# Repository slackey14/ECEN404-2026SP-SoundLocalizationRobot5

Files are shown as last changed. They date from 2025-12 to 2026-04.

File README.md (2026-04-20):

# Sound Localization Robot 5, Team 23

**Sound Rover** is an autonomous, omnidirectional robot powered by an ESP32-S3 Wroom. It uses a 4-microphone array to localize target sound frequencies via Phase-Gradient TDOA (SRP-PHAT beamforming) and navigates toward them using A* path planning, mecanum wheels, and ultrasonic obstacle avoidance.

## Features
* **Acoustic Localization:** 4-mic SRP-PHAT beamforming for 360° sound direction finding and distance estimation.
* **Omnidirectional Drive:** Mecanum wheel control for complex maneuvering and strafing.
* **Autonomous Navigation:** Real-time A* path planning, mapping, and destination re-calculation on the fly.
* **Obstacle Avoidance:** 4x Ultrasonic sensors (Front, Back, Left, Right) via hardware-driven edge interrupts.
* **Web Interface:** Built-in WiFi Access Point and HTTP server providing a live web UI with map visualization, manual controls, and live DSP configuration.

## Hardware Architecture
* **Microcontroller:** ESP32-S3 WROOM 1
* **Microphones:** 4x I2S Digital Microphones
* **Sensors:** 6x Ultrasonic Distance Sensors
* **Chassis:** 4WD Mecanum Wheel chassis with independent motor drivers (PWM/Dir)

## Software Stack
* **Framework:** ESP-IDF / FreeRTOS (via PlatformIO)
* **Concurrency:** * **Core 0:** WiFi AP, HTTP Server, and Sound DSP Task (I2S DMA + FFT + SRP-PHAT).
  * **Core 1:** Navigation Task (A* Routing, Motor Control, Obstacle Detection).

## Getting Started
1. Flash the firmware to your ESP32-S3 using PlatformIO.
2. Power on the Rover.
3. Connect your device to the newly created WiFi Access Point: `Sound_Rover` (Open network).
4. Open a web browser and navigate to `http://192.168.4.1`.
5. From the Web UI, you can manually drive the rover, view the live localized obstacle map, or click **Chase Sound Source** to begin autonomous acoustic tracking.

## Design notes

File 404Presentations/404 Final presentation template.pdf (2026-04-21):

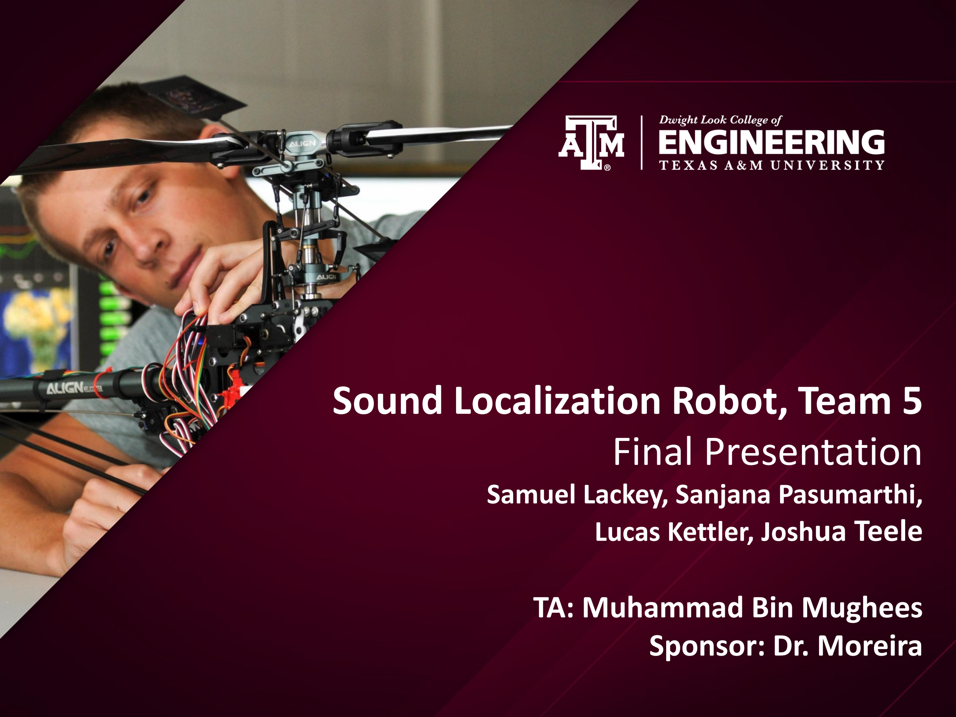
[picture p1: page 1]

# Sound Localization Robot, Team 5 Final Presentation

Samuel Lackey, Sanjana Pasumarthi,

# Lucas Kettler, Joshua Teele

# TA: Muhammad Bin Mughees Sponsor: Dr. Moreira

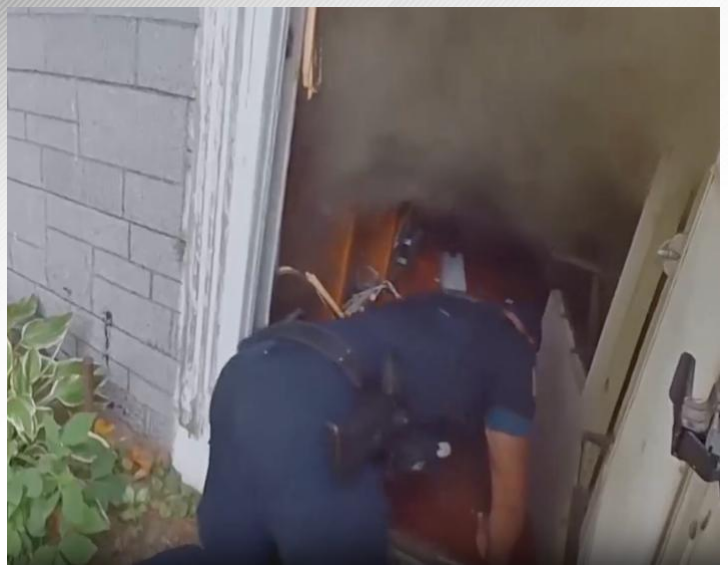
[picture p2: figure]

Figure 1. First responder crawls through smoke and broken glass to rescue elderly man from house fire (Independent TV)

# Problem: First Responders lack reliable methods for navigating dangerous environments, where visibility is limited, putting both their

safety and the victims at risk.

# Project Scope

# Our Solution: Building a Sound Localization robot that can hear distress calls, pinpoint their direction, and move toward them autonomously, allowing first responders to focus on saving lives

instead of risking theirs.

### •Keeps first responders safe by entering hazardous or toxic areas

first.

### •Reduces search and rescue time by avoiding exploring unnecessary paths •Reliable in low-visibility or high-

stress conditions (smoke, debris, noise).

*A smarter, safer, and faster way to locate victims, all while protecting rescuers and saving more lives.

# Integrated System Diagram:

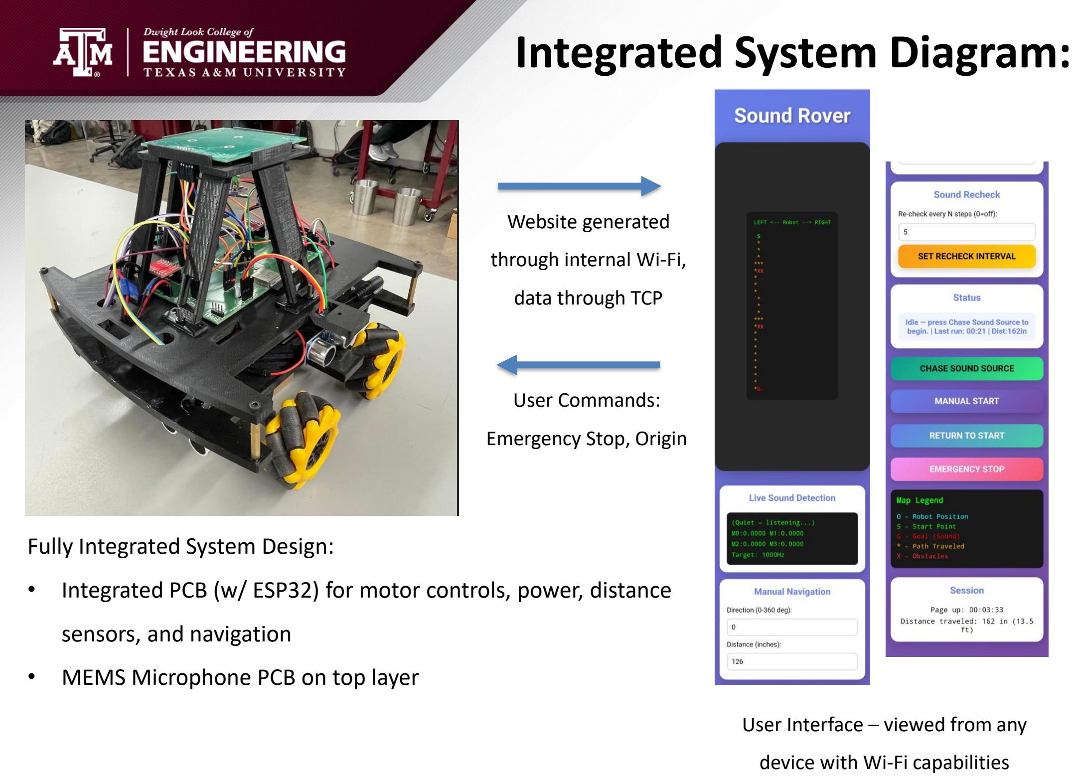
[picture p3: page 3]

## Fully Integrated System Design:

## - Integrated PCB (w/ ESP32) for motor controls, power, distance

## sensors, and navigation

## - MEMS Microphone PCB on top layer

### Website generated

through internal Wi-Fi,

### data through TCP

### User Interface – viewed from any

### device with Wi-Fi capabilities

### User Commands:

### Emergency Stop, Origin

# Navigation Software Subsystem Lucas Kettler

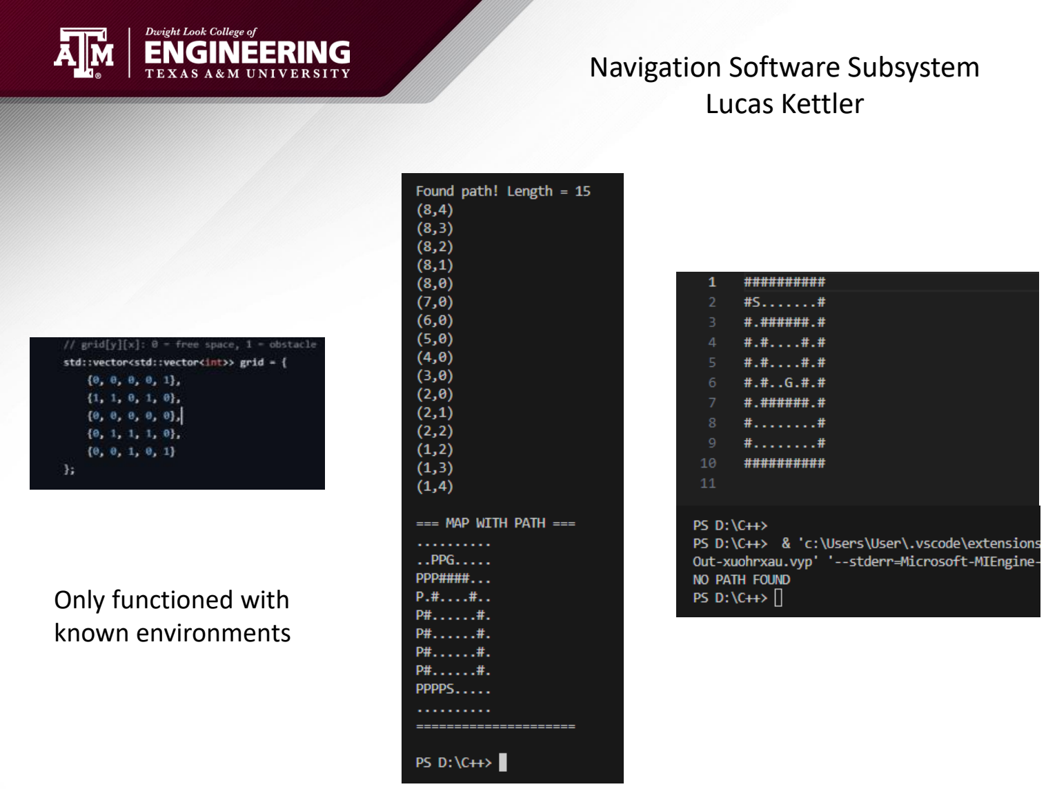
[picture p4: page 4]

## Only functioned with known environments

# Navigation Software Subsystem Lucas Kettler

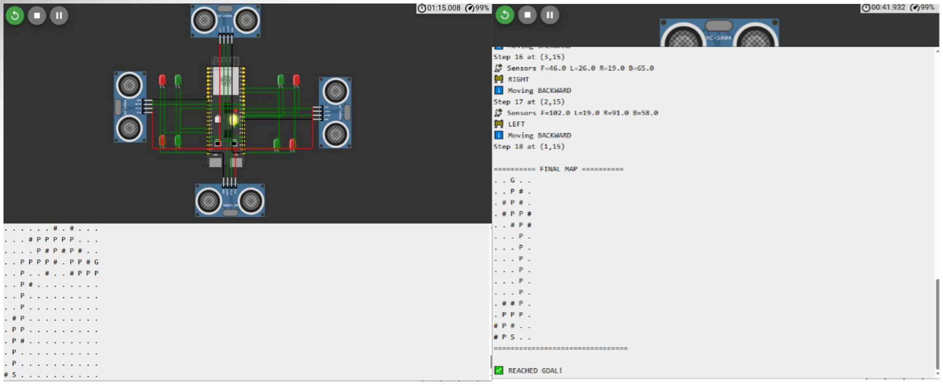
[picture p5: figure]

## No real world implementation at that time

# Navigation Software Subsystem Lucas Kettler

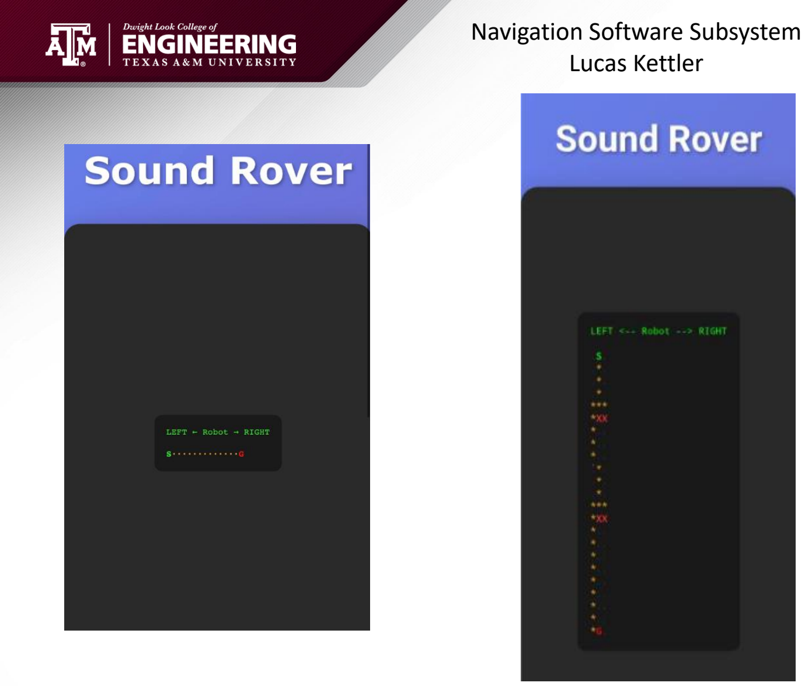
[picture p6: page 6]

# Motor Controls & Chassis Design & UI Subsystem Sanjana Pasumarthi

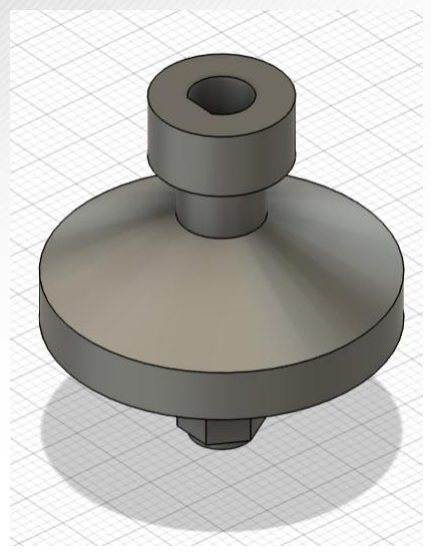
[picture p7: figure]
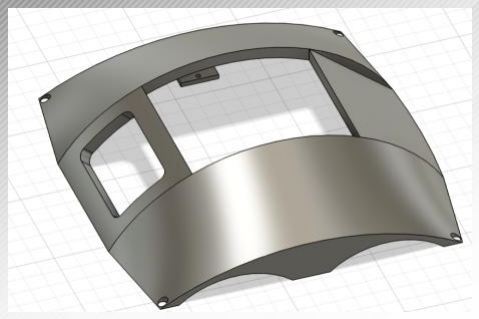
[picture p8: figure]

## - Physical Design of Rover - 2 layer Chassis Design - Strong Wheel axle - Dome Casing

## - Rover System - TCP socket generated from ESP Wi-fi - Webpage consists of multiple commands for user

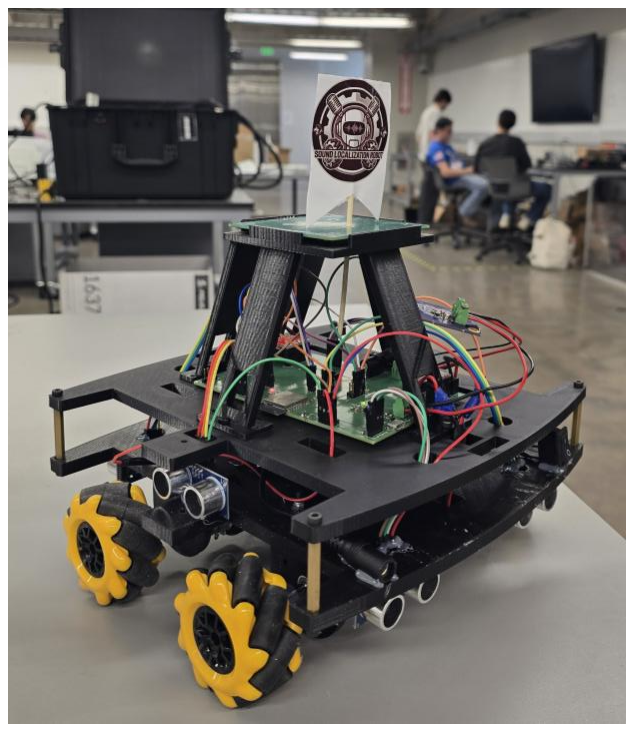
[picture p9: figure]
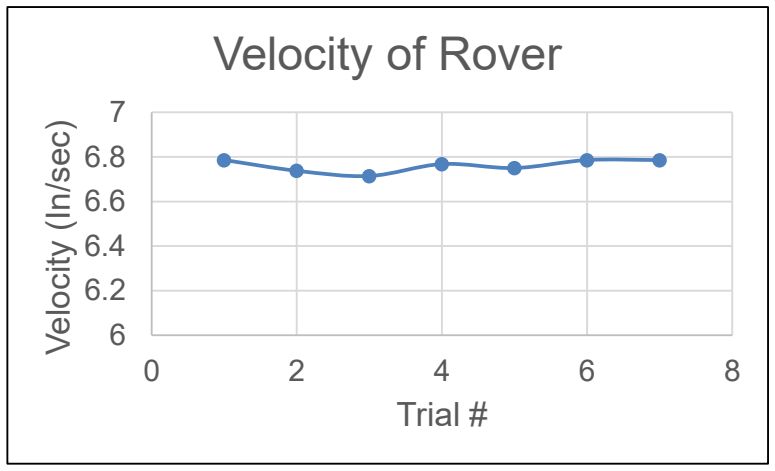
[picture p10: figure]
Velocity (In/sec); Trial #; Velocity of Rover

## Avg: 6.76 In/sec

# Motor Controls & Chassis Design & UI Subsystem

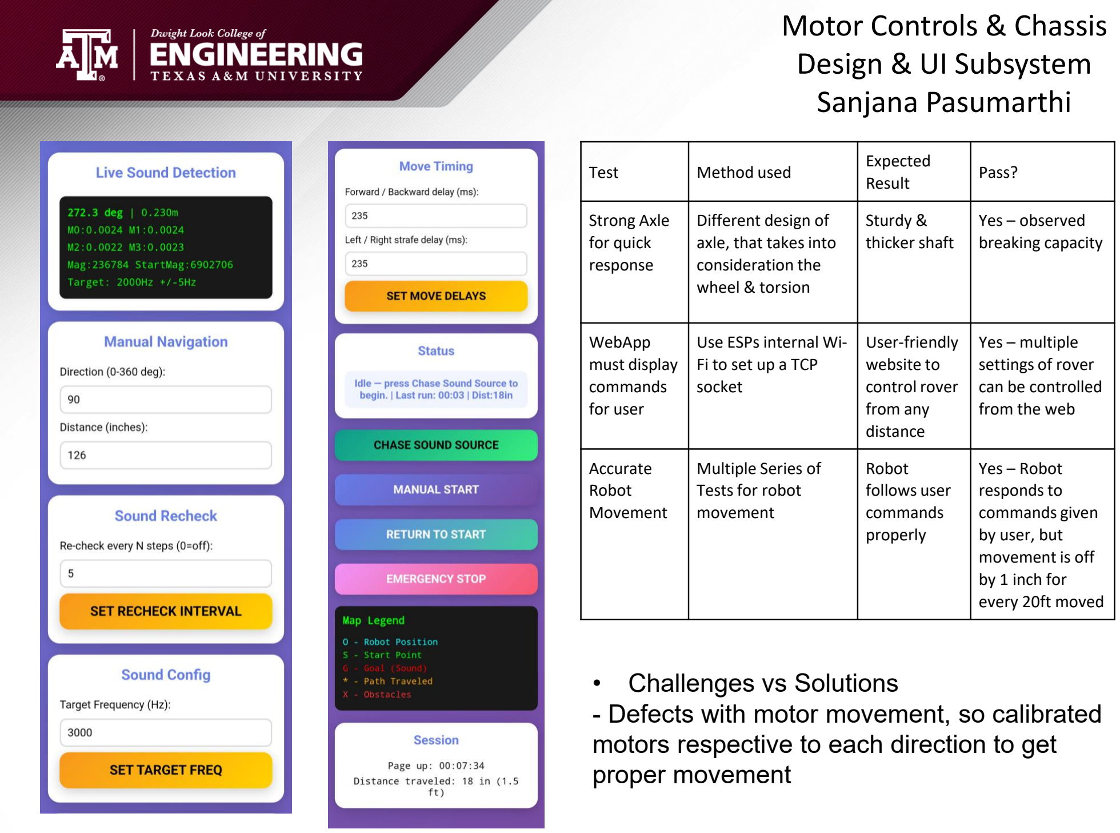
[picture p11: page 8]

# Sanjana Pasumarthi

Test | Method used | Expected Result | Pass?
Strong Axle for quick response | Different design of axle, that takes into consideration the wheel & torsion | Sturdy & thicker shaft | Yes – observed breaking capacity
WebApp must display commands for user | Use ESPs internal Wi-Fi to set up a TCP socket | User-friendly website to control rover from any distance | Yes – multiple settings of rover can be controlled from the web
Accurate Robot Movement | Multiple Series of Tests for robot movement | Robot follows user commands properly | Yes – Robot responds to commands given by user, but movement is off by 1 inch for every 20ft moved

## - Challenges vs Solutions - Defects with motor movement, so calibrated motors respective to each direction to get proper movement

# Input Signal Subsystem Samuel Lackey

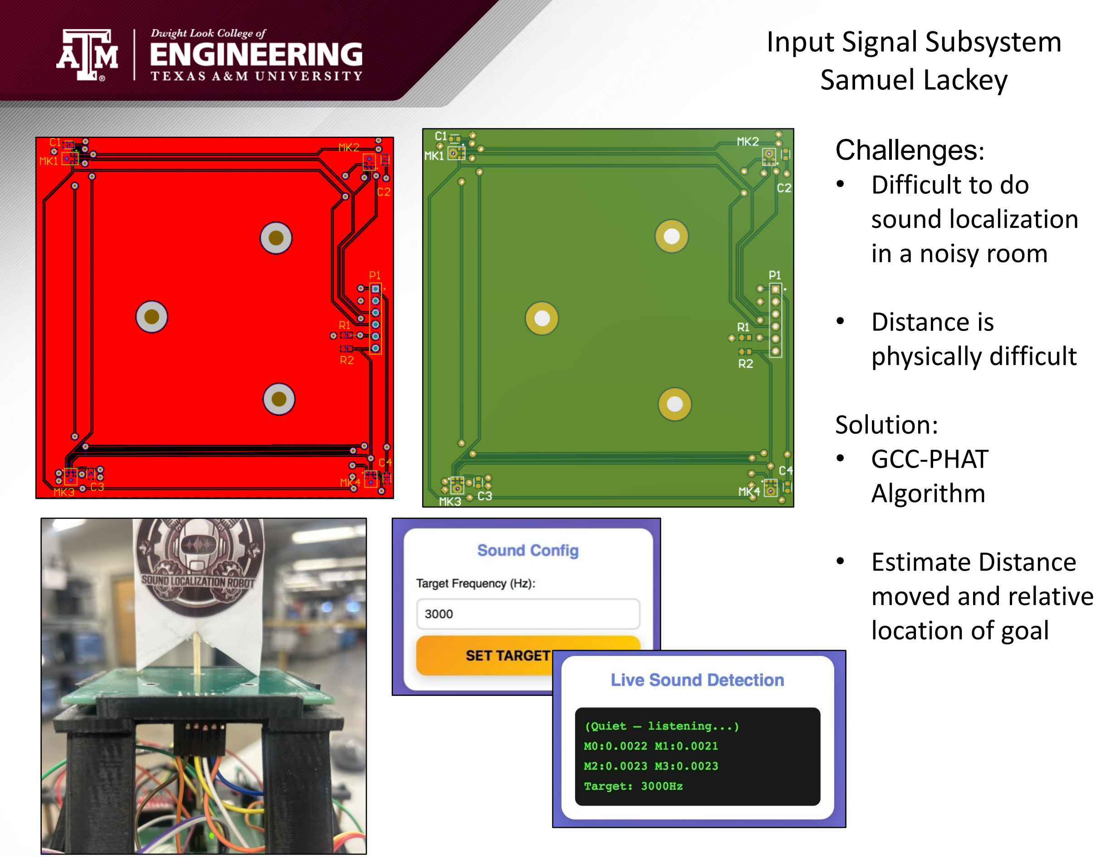
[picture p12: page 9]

## Challenges:

## - Difficult to do sound localization in a noisy room

## - Distance is physically difficult

## Solution: - GCC-PHAT Algorithm

## - Estimate Distance moved and relative location of goal

Test | Pass?
Microphone gives radial angle < 15° | 0° - ✓ 90° - ✓ 180° - ✓ 270° - ✓

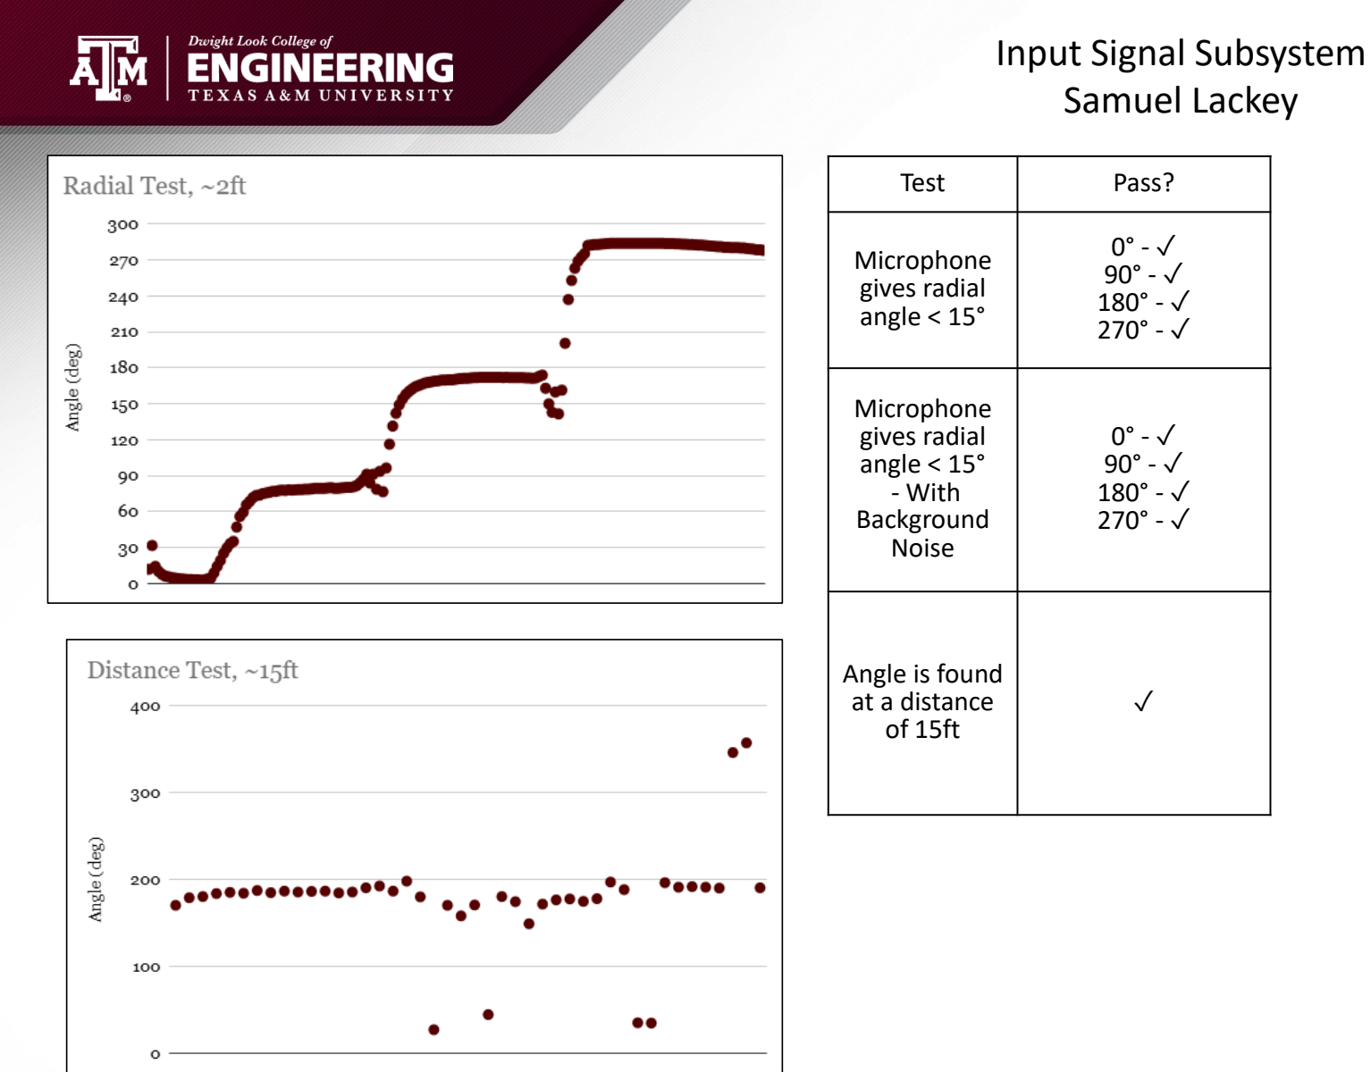
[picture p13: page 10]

Microphone gives radial angle < 15° - With Background Noise | 0° - ✓ 90° - ✓ 180° - ✓ 270° - ✓
Angle is found at a distance of 15ft | ✓

# Input Signal Subsystem Samuel Lackey

# Power & Distance Sensor & MCU Subsystem Joshua Teele

## Diagram of Power Flow in Whole System

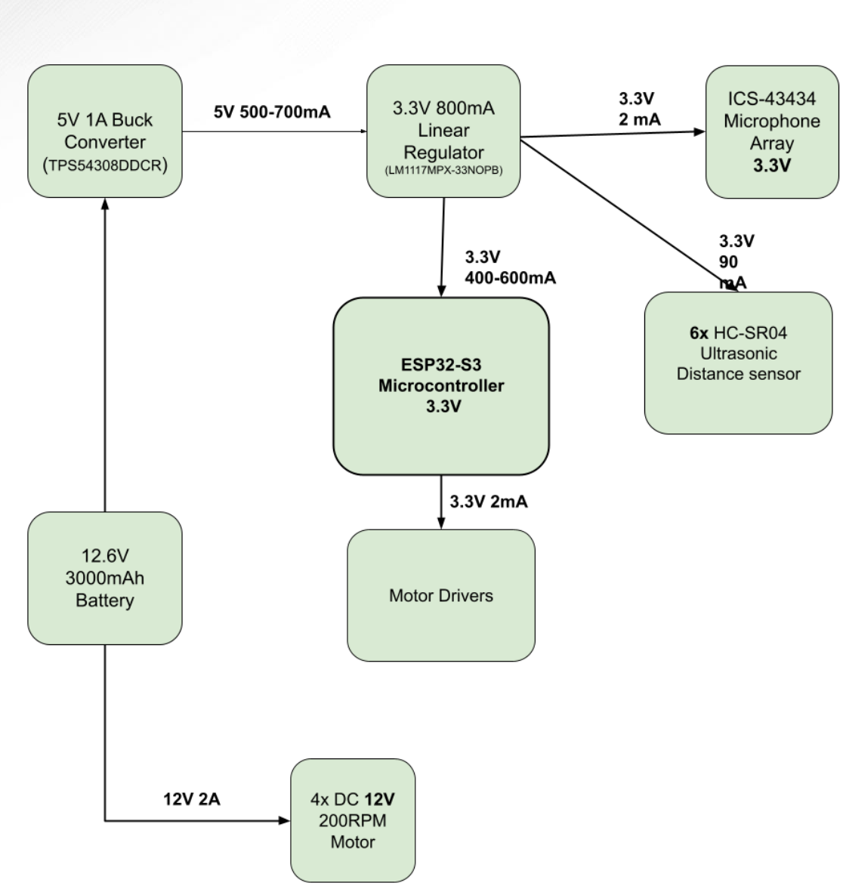
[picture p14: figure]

# Power & Distance Sensor & MCU Subsystem

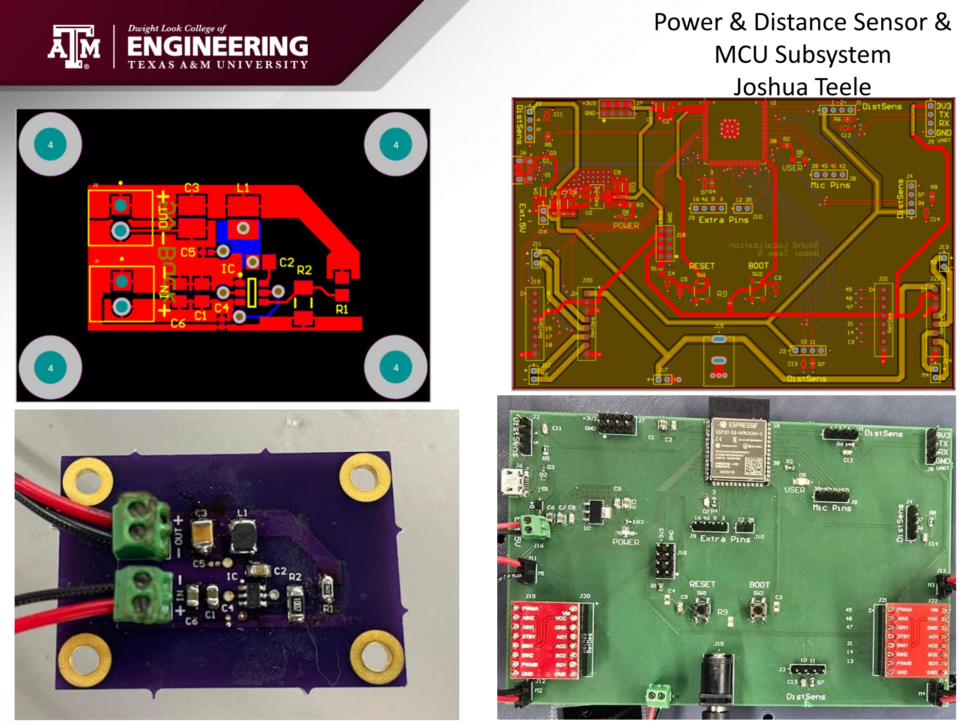
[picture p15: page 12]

# Joshua Teele

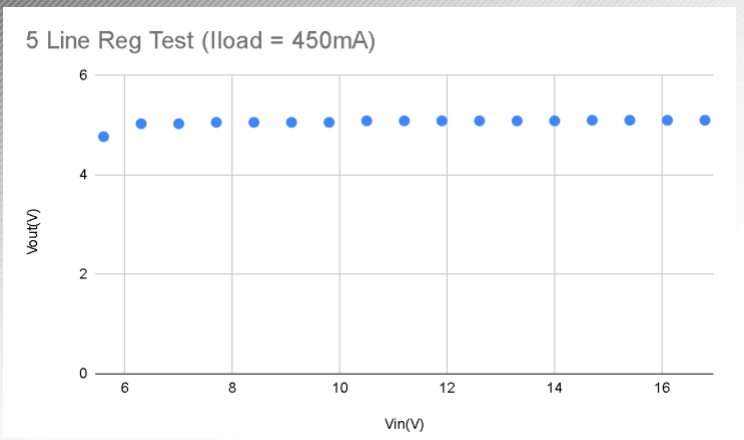
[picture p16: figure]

Test | Distance used | Expected Result | Pass?
Sensor outputs hig h when distance < 25.4 cm | 15 cm | High on all sensors | Sensor 1 - ✓ Sensor 2 - ✓ Sensor 3 - ✓ Sensor 4 - ✓
Sensor outputs low when distance > 25.4 cm | 35 cm | Low on all sensors | Sensor 1 - ✓ Sensor 2 - ✓ Sensor 3 - ✓ Sensor 4 - ✓

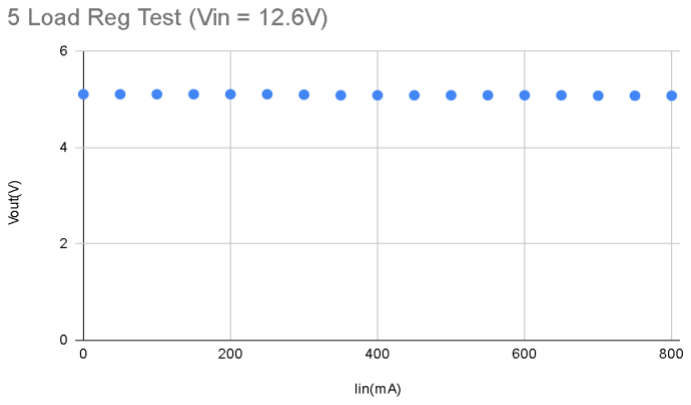
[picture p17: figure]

What happens at the bound ary for sensor | 25.4 cm | High on all sensors | Sensor 1 - High Sensor 2 - High Sensor 3 - High Sensor 4 - High
Slightly under boundary | 24.5 cm | Low on all sensors | Sensor 1 - ✓ Sensor 2 - ✓ Sensor 3 - ✓ Sensor 4 - ✓

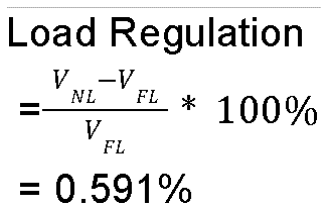
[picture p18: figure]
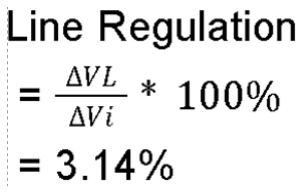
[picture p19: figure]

Slightly over boundary | 26.4 cm | High on all sensors | Sensor 1 - ✓ Sensor 2 - ✓ Sensor 3 - ✓ Sensor 4 - ✓
Multiple sensors | 25.4 cm | High on all combinations | ✓

# Power & Distance Sensor & MCU Subsystem Joshua Teele

## Challenges: - Placement of distance sensors to avoid obstacles

## Solutions: - Put on front and back where it can catch blind spots

# Power & Distance Sensor & MCU Subsystem

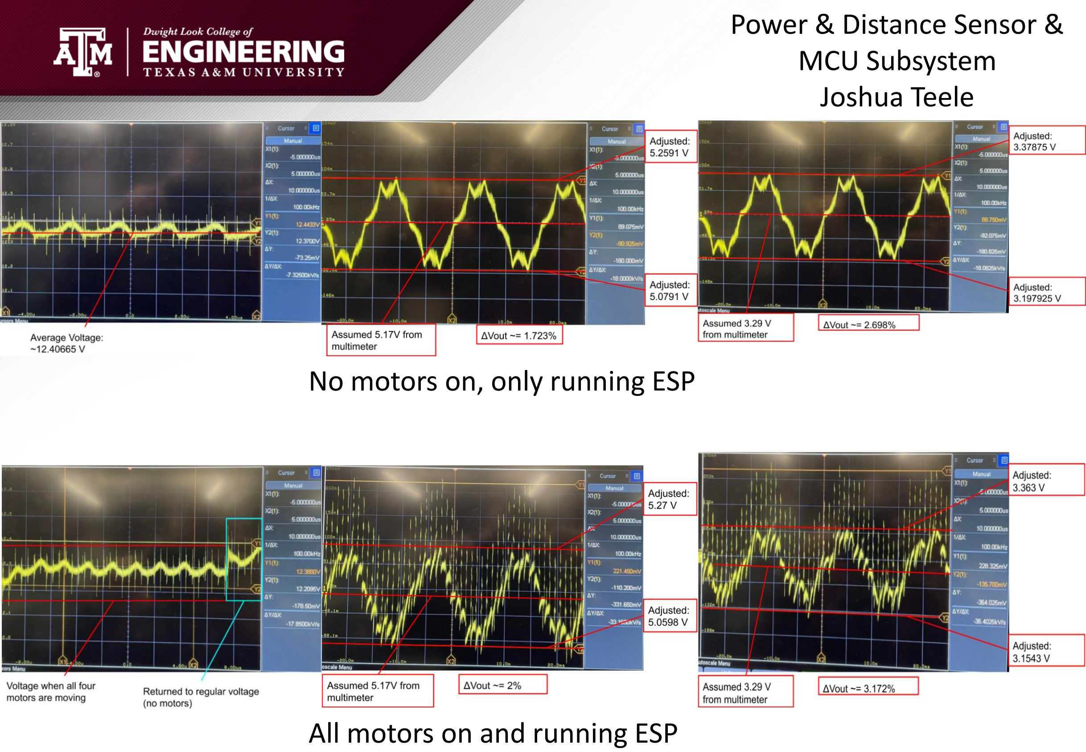
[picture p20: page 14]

# Joshua Teele

# No motors on, only running ESP

# All motors on and running ESP

# System

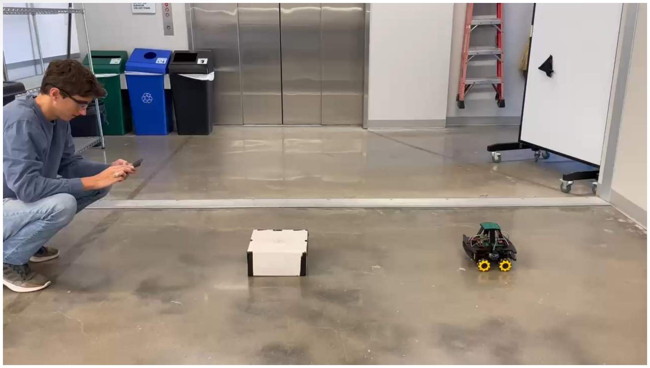
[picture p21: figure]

# System Testing

Test | Results

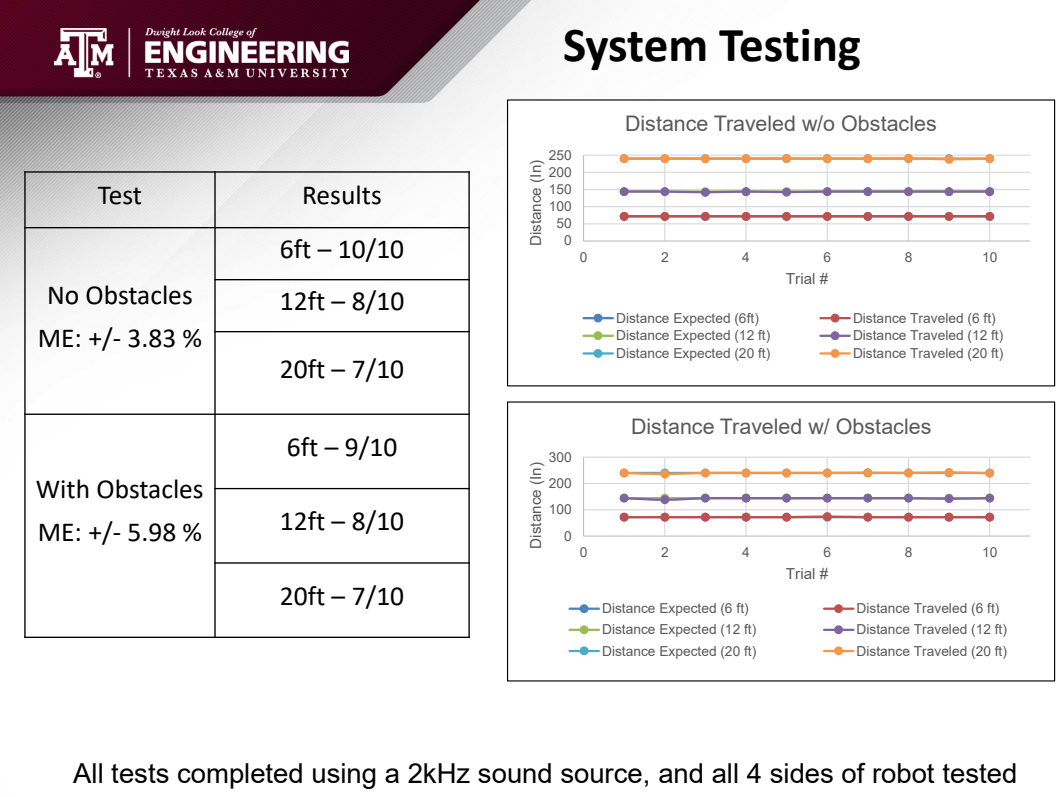
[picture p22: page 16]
With Obstacles; Distance (In); Trial #; Distance Expected (6ft); Distance Traveled (6 ft); Distance Expected (12 ft); Distance Traveled (12 ft); Distance Expected (20 ft); Distance Traveled (20 ft); Distance Expected (6 ft)

Distance Traveled w/o Obstacles

No Obstacles ME: +/- 3.83 % | 6ft – 10/10

Distance Traveled w/ Obstacles

All tests completed using a 2kHz sound source, and all 4 sides of robot tested

# Changes from 403:

# - Additional Distance Sensors

# - No 3.3 V Buck Converter

# - No Hall effect sensors

# - Using designed PCB Mic

# Array

# Current Status:

# - Integration Complete

# - Validation Complete

# - Finishing Touches such as

# addressing slight motor

# drift, and map display

# Conclusions

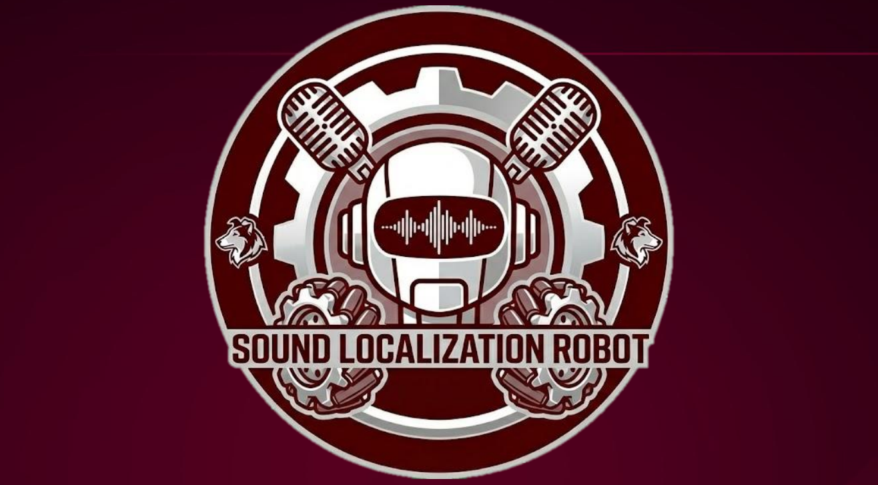
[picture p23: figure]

Thank You,

# Any Questions?

# Sound Localization Robot 5 – Team 23

# Lucas Kettler, Samuel Lackey, Joshua Teele, Sanjana Pasumarthi

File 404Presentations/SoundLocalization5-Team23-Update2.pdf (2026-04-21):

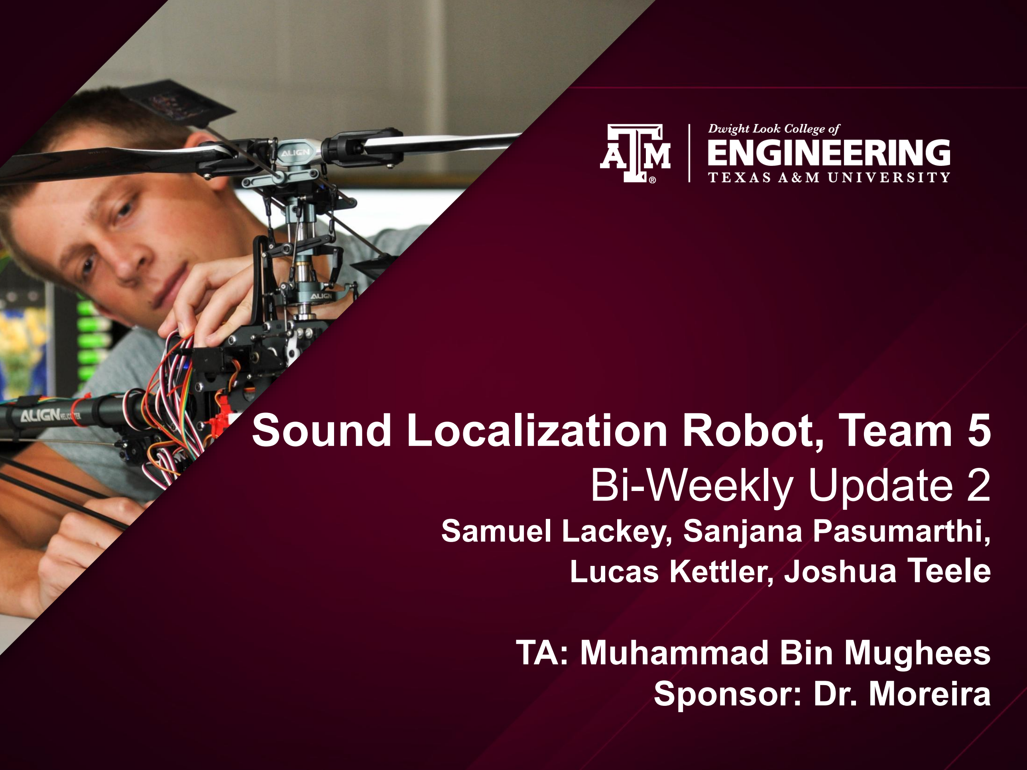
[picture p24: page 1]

# Sound Localization Robot, Team 5 Bi-Weekly Update 2

Samuel Lackey, Sanjana Pasumarthi,

### Lucas Kettler, Joshua Teele

## TA: Muhammad Bin Mughees Sponsor: Dr. Moreira


Figure 1. First responder crawls through smoke and broken glass to rescue elderly man from house fire (Independent TV)

### Problem: First Responders lack reliable methods for navigating dangerous environments, where visibility is limited, putting both their

safety and the victims at risk.

# Project Scope

### Our Solution: Building a Sound Localization robot that can hear distress calls, pinpoint their direction, and move toward them autonomously, allowing first responders to focus on saving lives

instead of risking theirs.

•Keeps first responders safe by entering hazardous or toxic areas first.
•Reduces search and rescue time by avoiding exploring unnecessary paths
•Reliable in low-visibility or high-stress conditions (smoke, debris, noise).

*A smarter, safer, and faster way to locate victims, all while protecting rescuers and saving more lives.

# Robot Sub Systems:


# Project Timeline


# Input Signal Software

Samuel Lackey
Accomplishments since last update : 15 Hours of Effort

Ongoing progress/problems and plans until the next presentation
- Completed Microphone Array PCB
- Adapted Sound Localization Algorithm into a single callable function
- Fully incorporate Signal Processing code into navigation subsystem

# Input Signal Software


Samuel Lackey

Microphone Array PCB Schematic

Microphone Array PCB 3D Design

Microphone Array
PCB Design

# Mechanical/ Motor Controls Subsystem

Sanjana Pasumarthi
Accomplishments since Last Update 12 hours of effort | Ongoing progress/problems and plans until the next presentation
- Completed 3D prints of all parts • Integrated some parts of the navigation system with the motor controls | • Still working on integrating the code with Lucas • Have the webapp’s UI complete and display the data (magnitude & direction, pathway, time duration)

# Mechanical/ Motor Controls Subsystem


Sanjana Pasumarthi

- Two-part set up to hold the isolated microphone array
- Top stand is screwed onto the top layer of the chassis
- Set-up the Wi-Fi module for the webapp, still working on the UI
- Implemented necessary
pauses before the motors’
changes direction

# Navigation Software Subsystem

Lucas Kettler
Accomplishments since Last Update 8 hrs of effort | Ongoing progress/problems and plans until the next presentation
- Integration of Motor Controls (Untested) • Integration of Webapp (Untested) | • Validate integration of Motor controls and webapp • Integration of code with Input Software/Sensor Software Code

### Navigation Software Subsystem Lucas Kettler


# Power & Distance Sensor Subsystem

Joshua Teele
Accomplishments since Last Update
10 hrs of effort

Ongoing progress/problems and plans until the next presentation
- Completed PCB design of MCU
- Ordered MCU PCB and
components
- Solder PCB and test with multimeter
- Test individual subsystems on new MCU
- Ongoing: Integrate distance sensor code with navigation software

# Power & Distance Sensor Subsystem


Joshua Teele

# Parts and PCB

Part | Est. Arrival
MCU PCB | Feb 6th
Components for MCU PCB | Acquired
Microphone Array PCB | Feb 10th
Components for Mic Array PCB | Feb 10th

# Execution Plan


# Validation Plan


Thank You,

# Any Questions?

## Sound Localization Robot 5 – Team 23

Lucas Kettler, Samuel Lackey, Joshua Teele,

## Sanjana Pasumarthi

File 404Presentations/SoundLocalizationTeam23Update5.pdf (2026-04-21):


## Team 23: Sound Localization Robot Bi-Weekly Update 5

Samuel Lackey, Sanjana Pasumarthi, Lucas Kettler,

### Joshue Teele

### Sponsor: Dr. Moreira TA: Muhammed Bin Mughees


Figure 1. First responder crawls through smoke and broken glass to rescue elderly man from house fire (Independent TV)

### Problem: First Responders lack reliable methods for navigating dangerous environments, where visibility is limited, putting both their

safety and the victims at risk.

# Project Scope

### Our Solution: Building a Sound Localization robot that can hear distress calls, pinpoint their direction, and move toward them autonomously, allowing first responders to focus on saving lives

instead of risking theirs.

•Keeps first responders safe by entering hazardous or toxic areas first.
•Reduces search and rescue time by avoiding exploring unnecessary paths
•Reliable in low-visibility or high-stress conditions (smoke, debris, noise).

*A smarter, safer, and faster way to locate victims, all while protecting rescuers and saving more lives.

# Project Timeline

Subsystem
Designs and
Testing
(completed
1/29)

Integration of
Motor Control,
Navigation
(completed
2/5)

Integration of
Sound
Algorithm,
Navigation
(completed
2/19)

Final
Integration
(completed
3/3)

System Test
(completed
3/10)

Validation
(to complete
by 3/31)

Demo and
Report
(to complete
by 4/5)

# SYSTEM Validation Plan


# Validation

3.2.2.1 Accurate Robot
Movement

Robot moves in intended direction determined by program

Series of coordination
tests for the robot to
move to the sound
source

TESTED Full
Team

Robot moves roughly 1m off every 20m in testing. This can be fine tuned in code

3.2.2.3 Structurally strong Robot

Wheel shaft does not break easily, no unintended movement from motors

Test robot with obstacles
and quick movement | TESTED | Sanjana

3.2.2.2

Constant
Response rate of
robot

Robot has a constant rate of response with +/- 5% of average time

Multiple trials of measuring time it takes for rover to change status

NOT
TESTED

Full
Team

Stronger shafts hold more weight and pressure, naturally fits into wheel for more grip, removing need for adhesive

# Validation

Map updated seamlessly with the live movements, with and without obstacles while showing distance travelled

3.2.1. 3 | Obstacle Detection | Verify robot halts movement at the node prior to an object | Isolated test with robot trying to drive around obstacle to a goal | TESTED | Lucas, Joshua, Sanjana
3.2.1. 4 | Grid Mapping | Verify the robot updates a grid map for the web app | completion of path View output of webapp upon | TESTED | Lucas, Sanjana
3.2.1. 5 | Webapp | The webapp must show the angle, estimate distance, and control the robot. | Run the program and connect to Wi-Fi, access the webapp, and move. | TESTED | Sam, Sanjana


# Validation

It’s difficult to achieve true perfect angle calculation in noisy rooms, but robot will still detect sound source well.

3.2.1.1 | DOA Angle Accuracy | All 5 tests must log a detected angle within an 3.6° | Place speaker playing 450Hz tone at a known angle, and 0.5m distance. Run the detection test 5 times | TESTED | Sam
3.2.1.2 | DOA With Backgrou nd Noise | All 5 tests must log a detected angle within an 3.6° | Place speaker playing 450Hz tone at a known angle, and 0.5m distance while separate 550Hz tone is playing. Repeat 5 times | UNTESTED | Sam
3.2.1.6 | Robot Distance | The robot must finish moving < 0.5 m from the sound source. | Play the sound source, allow the robot to move at different distances and angles. | TESTED | Sam


# Validation


3.2.3. 3.1 | Input Voltage(US B) | Ensure voltage at USB port is above 4.75V (minimum needed voltage for linear regulator) | Use multimeter to test output of buck converter | TESTED | Joshua
3.2.3. 3.2 | Input Voltage(DC jack) | Ensure voltage at DC jack is between 10.8 and 13.2 V (+/-10% of motor voltage) | Use multimeter to test output of DC jack | TESTED | Joshua

# Integrated System Diagram:


Fully Integrated System Design:

- Integrated PCB (w/ ESP32) for motor

controls, power, distance sensors, and

navigation

- Microphone PCB on top layer (not displayed)

Website generated

through internal Wi-Fi

User Interface – viewed from any

device with Wi-Fi capabilities

User Commands:

Emergency Stop, Origin

# Input Signal Software

Samuel Lackey
Accomplishments since last update : 20 Hours of Effort | Ongoing progress/problems and plans until the next presentation
- Fully Integrated and tested new microphone PCB with the robot. | • Continue testing, and improving • I need to work out edge cases and reliability

# Mechanical/ Motor Controls Subsystem

Sanjana Pasumarthi

Accomplishments since last update 15 hrs of effort | Ongoing progress/problems and plans until the next presentation
- Validated Structural Integrity of chassis design • Completed UI • Validated movement of motors corresponding to their movement | • On-going tests to determine optimal duration of motors for accurate movement • Designing casing to cover set-up

# Navigation Software Subsystem

Lucas Kettler

Accomplishments since last update 13 hrs of effort

Ongoing progress/problems and plans until the next presentation

- Validated Grid map live updates
- Added a run timer and return to start function
- Assisted in tests of varying distances with and without obstacles
- Validate Grid map expansion for demo

# Power & Distance Sensor Subsystem

Joshua Teele

Accomplishments since Last Update 12 hrs of effort | Ongoing progress/problems and plans until the next presentation
- Helped other work on fully integrated robot • Changed up wiring on the chassis to make it look neater | • Keep testing and sort out any issues with robot

# Execution Plan



Thank You,

# Any Questions?

## Sound Localization Robot 5 – Team 23

Lucas Kettler, Samuel Lackey, Joshua Teele,

## Sanjana Pasumarthi

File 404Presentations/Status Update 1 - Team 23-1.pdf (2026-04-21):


## Sound Localization Robot 5, Team 23

Samuel Lackey, Sanjana Pasumarthi,

### Lucas Kettler, Joshua Teele

## TA: Muhammad Bin Mughees Sponsor: Dr. Moreira


Figure 1. First responder crawls through smoke and broken glass to rescue elderly man from house fire (Independent TV)

### Problem: First Responders lack reliable methods for navigating dangerous environments, where visibility is limited, putting both their

safety and the victims at risk.

# Project Scope

### Our Solution: Building a Sound Localization robot that can hear distress calls, pinpoint their direction, and move toward them autonomously, allowing first responders to focus on saving lives

instead of risking theirs.

•Keeps first responders safe by entering hazardous or toxic areas first.
•Reduces search and rescue time by avoiding exploring unnecessary paths
•Reliable in low-visibility or high-stress conditions (smoke, debris, noise).

*A smarter, safer, and faster way to locate victims, all while protecting rescuers and saving more lives.

# Robot Sub Systems:


# Major Project Implementations for 404

- No longer using 3.3V buck converter
- Changed from circular mic array to new designed mic

array

- Integrated webapp with information portraying:

location, angle, distance, current direction movement,

alert user once destination is reached, and controls.

- Robot will move to sound source in & out of sight,

and avoid obstacles

- Robot movement with periodical listening capability

# Project Timeline


# Input Signal Software

Samuel Lackey
Accomplishments since 403
5 Hours of Effort

Ongoing progress/problems and plans until the next presentation
- Algorithm detects angles within 3.6°
- A specific frequency can be isolated
- A rough distance can be
calculated
- Completed schematic for
Microphone Array
- Complete PCB layout for
microphone array
- Work with Lucas to merge codebase

# Input Signal Software


Samuel Lackey

Microphone Array PCB Schematic

Microphone Array Angle Test

# Mechanical/ Motor Controls Subsystem

Sanjana Pasumarthi
Accomplishments since 403
6 hours of effort

Ongoing progress/problems and plans until the next presentation
- Sound rover moves in all directions, given the remote command from website, in-built LED to show connectivity status
- All parts such as the base, motor clamps and wheel shafts are 3D printed
- Established local Wi-Fi
connection on ESP32, stable at 20 feet radius, response speed of 0.24 seconds
- Have a verified design for an PCB that integrates the power and the motor controls
- Integrating the motor control firmware with the navigation & input signal software
- Update design & 3D print parts for rover

# Mechanical/ Motor Controls Subsystem

Sanjana Pasumarthi; Linear Velocity; (Ft/Sec); Trial #; 16 Velocity ⁽Ft/ Sec⁾; 16 Velocity ⁽Ft/Sec⁾; Diagonal Trials; Diagonal Directions; Angular Velocity; (Rad/sec); Sec); Mean: 3.4305 +/- 0.0126 Rad/Sec; Time (Sec); Feet; Trial #1; Trial #2; Trial #3; Mean: 0.243 +/- 0.0457 Sec

Velocity (Ft/Sec)

Mean: 2.4831 +/- 0.0064 Ft/ Sec

Forward/ Backward Directions

*measured distance of 6.5 ft

Mean: 2.3135 +/- 0.0258 Ft/ Sec

Left/ Right Directions

Mean: 1.7158 +/- 0.0173 Ft/ Sec

*measured distance of 1 ft

Recieved Command Time (Sec)

Angular Velocity (Rad/

Linear Velocity (3.5 in. ~ 0.2961 ft)
Mean: 0.1592 +/- 0.0005 Ft/Sec

*measured time for one complete
rotation (2*π radians)

# Navigation Software Subsystem

Lucas Kettler
Accomplishments since 403 6 hrs of effort | Ongoing progress/problems and plans until the next presentation
- Implementation of incremental A* algorithm with grid mapping and real time expansion • Wide range of simulations completed using LEDs and simulated sensor input | • Integration of code with Motor Controls/WebApp Code • Integration of code with Input Software Code

### Navigation Software Subsystem Lucas Kettler


## - Red LED – Backwards - Green LED – Forwards - Yellow LED – Obstacle - Logic works as intended but requires many changes to be adapted to a real-world robot

# Power & Distance Sensor Subsystem

Joshua Teele
Accomplishments since 403 6 hrs of effort | Ongoing progress/problems and plans until the next presentation
- Completed schematic for MCU PCB • Designed, soldered, and tested 3.3V and 5V buck converter (403) • Created code for distance sensors (403) | • Finish designing and routing MCU PCB • Integrate distance sensor code with navigation software

# Power & Distance Sensor Subsystem


Joshua Teele

# Parts and PCB

Part | Est. Arrival
MCU PCB | Feb 26th
Components for MCU PCB | Feb 19th
Microphone Array PCB | Feb 26th
4x ICS-43434 Mics | Feb 19th
4x 0.1µF Capacitor | Feb 19th

# Execution Plan


# Validation Plan


Thank You,

# Any Questions

## Sound Localization Robot 5 – Team 23

Lucas Kettler, Samuel Lackey, Joshua Teele,

## Sanjana Pasumarthi

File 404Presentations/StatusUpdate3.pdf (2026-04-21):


# Sound Localization Robot, Team 5 Bi-Weekly Update 3

Samuel Lackey, Sanjana Pasumarthi,

### Lucas Kettler, Joshua Teele

## TA: Muhammad Bin Mughees Sponsor: Dr. Moreira


Figure 1. First responder crawls through smoke and broken glass to rescue elderly man from house fire (Independent TV)

### Problem: First Responders lack reliable methods for navigating dangerous environments, where visibility is limited, putting both their

safety and the victims at risk.

# Project Scope

### Our Solution: Building a Sound Localization robot that can hear distress calls, pinpoint their direction, and move toward them autonomously, allowing first responders to focus on saving lives

instead of risking theirs.

•Keeps first responders safe by entering hazardous or toxic areas first.
•Reduces search and rescue time by avoiding exploring unnecessary paths
•Reliable in low-visibility or high-stress conditions (smoke, debris, noise).

*A smarter, safer, and faster way to locate victims, all while protecting rescuers and saving more lives.

# Robot Sub Systems:


# Project Timeline


# Input Signal Software

Samuel Lackey
Accomplishments since last update : 15 Hours of Effort

Ongoing progress/problems and plans until the next presentation
- Completed Microphone Array PCB
- Adapted Sound Localization Algorithm into a single callable function
- Fully incorporate Signal Processing code into Navigation subsystem
- The new Microphone PCB is not fully functional yet

# Input Signal Software


Samuel Lackey

Microphone Array PCB 3D Design

Microphone Array PCB

Only 2/4 Mics are
outputting data
- Check solder connections
- Resolder non-functional
mics

# Mechanical/ Motor Controls Subsystem

Sanjana Pasumarthi
Accomplishments since Last Update 11 hours of effort | Ongoing progress/problems and plans until the next presentation
- Set back with some of the components failing, had to order replacements and rewire for testing • Basic UI is complete to display information | • Program a method to record pathway trace for the rover to return to its origin • Integrating the controls with Lucas’s Code

# Mechanical/ Motor Controls Subsystem

Sanjana Pasumarthi


- Final UI design of website accessible through connect of ESP wifi module
- Includes emergency stop, pathway of rover, return to origin button, magnitude and direction of sound source

# Navigation Software Subsystem

Lucas Kettler

Accomplishments since Last Update 10 hrs of effort | Ongoing progress/problems and plans until the next presentation
- Partial integration of Input software/webapp • Integration of Sensor code | • Validate integration of subsystems • Debug integration components

### Navigation Software Subsystem Lucas Kettler


# Power & Distance Sensor Subsystem

Joshua Teele
Accomplishments since Last Update 10 hrs of effort | Ongoing progress/problems and plans until the next presentation
- Solder PCB and test with multimeter • Tested distance sensor code on new MCU | • Test rest of individual subsystems on new MCU • Ongoing: Integrate distance sensor code with navigation software

# Power & Distance Sensor Subsystem

Joshua Teele


# Execution Plan


# Validation Plan


Thank You,

# Any Questions?

## Sound Localization Robot 5 – Team 23

Lucas Kettler, Samuel Lackey, Joshua Teele,

## Sanjana Pasumarthi

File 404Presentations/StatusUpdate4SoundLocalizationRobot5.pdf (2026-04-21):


# Sound Localization Robot, Team 5 Bi-Weekly Update 4

Samuel Lackey, Sanjana Pasumarthi,

### Lucas Kettler, Joshua Teele

## TA: Muhammad Bin Mughees Sponsor: Dr. Moreira


Figure 1. First responder crawls through smoke and broken glass to rescue elderly man from house fire (Independent TV)

### Problem: First Responders lack reliable methods for navigating dangerous environments, where visibility is limited, putting both their

safety and the victims at risk.

# Project Scope

### Our Solution: Building a Sound Localization robot that can hear distress calls, pinpoint their direction, and move toward them autonomously, allowing first responders to focus on saving lives

instead of risking theirs.

•Keeps first responders safe by entering hazardous or toxic areas first.
•Reduces search and rescue time by avoiding exploring unnecessary paths
•Reliable in low-visibility or high-stress conditions (smoke, debris, noise).

*A smarter, safer, and faster way to locate victims, all while protecting rescuers and saving more lives.

# Integrated System Diagram:


Fully Integrated System Design:

- Integrated PCB (w/ ESP32) for motor

controls, power, distance sensors, and

navigation

- Microphone PCB on top layer (not displayed)

Website generated

through internal Wi-Fi


User Interface – viewed from

any device with Wi-Fi

capabilities

User Commands:

Emergency Stop, Origin

# Project Timeline


# Input Signal Software

Samuel Lackey
Accomplishments since last update : 35 Hours of Effort

Ongoing progress/problems and plans until the next presentation

- Soldered on Microphone PCB
- Tested Algorithm on new PCB
- Integrated algorithm into team’s

code

- Continue testing, and improving
- Not very accurate with current

implementation – Need to smooth

more for direction

# Input Signal Software


Samuel Lackey

Microphone Array PCB 3D Design

Microphone Array PCB

All Mics are now working as expected

# Mechanical/ Motor Controls Subsystem

Sanjana Pasumarthi
Accomplishments since Last Update
25 hours of effort

Ongoing progress/problems and plans until the next presentation
- Sub-system is complete, all systems are integrated
- Reprinting of 3D parts for better fit of the parts
- Testing optimal pauses and timing of movement
- More progress on UI, still making changes to certain visuals
- Improve the accuracy of the robot and bring it to its final settings
- Program the robot to be able to return to its original location

# Mechanical/ Motor Controls Subsystem


Sanjana Pasumarthi

- Final UI design of website

accessible through connect

of ESP Wi-Fi module

- Constantly updated map

after every node

- Some things will be

removed in the final design,

as they are used for just

the testing process

- Phone View

# Navigation Software Subsystem

Lucas Kettler

Accomplishments since Last Update 25 hrs of effort | Ongoing progress/problems and plans until the next presentation
- Completed/Validated integrations | • Improve accuracy of integrated system • Perform debugging

### Navigation Software Subsystem Lucas Kettler


- 90 degrees, 126 inches away destination input (Go right 14 nodes)
- Before input software integration
- Space for map expansion

# Power & Distance Sensor Subsystem

Joshua Teele
Accomplishments since Last Update 25 hrs of effort | Ongoing progress/problems and plans until the next presentation
- Tested all subsystems on MCU • Attached all subsystems to MCU for integration | • Help other work on fully integrated robot • Fix up wiring and buck converter placement on the chassis to make it look neater

# Power & Distance Sensor Subsystem

Joshua Teele


# Video of Navigation


# Execution Plan


# Validation Plan



Thank You,

# Any Questions?

## Sound Localization Robot 5 – Team 23

Lucas Kettler, Samuel Lackey, Joshua Teele,

## Sanjana Pasumarthi

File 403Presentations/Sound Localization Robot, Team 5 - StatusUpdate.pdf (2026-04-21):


# Sound Localization Robot, Team 5

Samuel Lackey, Sanjana Pasumarthi,

## Lucas Kettler, Joshua Teele

## TA: Fahrettin Ay

## Sponsor: Dr. Moreira

# - Problem statement: First Responders lack reliable methods for navigating in dangerous environments where visibility is limited or obstructed, putting both their

safety and the victims at risk.


Figure 1. First responder crawls through smoke and broken glass to rescue elderly man from house fire (Independent TV)

## Solution proposal: Building a Sound Localization robot that can hear distress calls, pinpoint their

direction, and move toward them autonomously,

## allowing first responders to focus on saving lives

instead of risking theirs.

•Keeps first responders safe by entering hazardous or toxic areas first. •Speeds up rescue operations by directly moving toward detected sounds.
•Reduces search and rescue time by avoiding exploring unnecessary paths.
•Improves survival rates, victims are found faster, thus treated faster. •Reliable in low-visibility or high-stress conditions (smoke, debris, noise).

*A smarter, safer, and faster way to locate victims, all while protecting rescuers and saving more lives.

# Robot Sub Systems:


# Input Signal Software

Samuel Lackey

Accomplishments since start:

### 25 Hours of Effort

Ongoing progress/problems and plans until the next presentation:

- TDOA algorithm working within 3.6° accuracy.
- Flashed software onto ESP32-S3 for verification.
- Flash a simple TDOA algorithm on ESP32 connected to UMA-8 microphone.
- Finalize JTAG pin configuration
- Add distance calculation to algorithm

# Input Signal Software


Samuel Lackey

UMA-8 Microphone

# Navigation Software

Lucas Kettler

Accomplishments since midterm presentation: 26 Hours | Ongoing progress/problems and plans until the next presentation:
- A* algorithm implemented • Expanding node map added • Simulation with random obstacles, goal outside initial map, and simulated sensor input | • Software to hardware application and debugging

# Navigation Software


Figure 1. A* visualization "Easy A*(Star) Pathfinding"

Lucas Kettler

Figure 2. Expanding grid map | Figure 3. Example Output

Accomplishments since start:

### 28 Hours of Effort

Ongoing progress/problems and plans until the next presentation:

- Realized that funnel is not necessary
- All necessary parts are ordered, and 3D models are currently being printed
- Developed test code to control the wheel motors, determined the pins used on the
microcontroller and its
interconnectivity with the motor drivers
- Assemble the robot, and place all components together to ensure everything fits
- Test motor control systems to see if it can complete basic directionality & integrate it with the navigation software

# Mechanical/ Motor Controls Subsystem

Sanjana Pasumarthi

## Mechanical/ Motor Controls Subsystem


Sanjana Pasumarthi

TB6612FNG (F)

TB6612FNG (B)

ESP 32

Right
Front
Motor

Left
Front
Motor

Right
Rear
Motor

Left
Rear
Motor
TB6612FNG (F) | ESP32
PWMA | GP19
AI1 | GP32
AI2 | GP23
BI1 | GP33
BI2 | GP25
PWMB | GP26
TB6612FNG (R) | ESP32
PWMA | GP27
AI1 | GP12
AI2 | GP14
BI1 | GP13
BI2 | GP2
PWMB | GP4

Power
Source
AI1/ BI1 | AI2/ BI2 | Direction
Low | Low | Off
High | Low | Forward
Low | High | Reverse
High | High | Stop/ Brake
Direction | AI1 (RF) | AI2 (RF) | BI1 (LF) | BI2 (LF) | AI1 (RR) | AI2 (RR) | BI1 (LR) | BI2 (LR)
Forward | 1 | 0 | 1 | 0 | 1 | 0 | 1 | 0
Backward | 0 | 1 | 0 | 1 | 0 | 1 | 0 | 1
Left | 1 | 0 | 0 | 1 | 0 | 1 | 1 | 0
Right | 0 | 1 | 1 | 0 | 1 | 0 | 0 | 1

*Brushed
DC Motors

# Power System and Distance Sensors

Joshua Teele

Accomplishments since last presentation:

### 25 Hours

Ongoing progress/problems and plans until the next presentation:

- Found required voltage and current requirements for the devices
- Designed 5V and 3.3V buck converter PCBs for powering devices
- Order PCBs to be made and test them
- Put together the power system on the robot
- Write code for the distance sensors and test them

# Power System and Distance Sensors


5V 600mA Buck Converter Design | 3.3V 200mA Buck Converter Design

Joshua Teele

# Execution plan


# Validation Plan


Thank You,

# Any Questions?

## Sound Localization Robot 5 – Team 23

Samuel Lackey, Lucas Kettler, Joshua Teele,

## Sanjana Pasumarthi

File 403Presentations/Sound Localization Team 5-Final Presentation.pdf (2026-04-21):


# Sound Localization Robot, Team 5

Samuel Lackey, Sanjana Pasumarthi,

# Lucas Kettler, Joshua Teele

# TA: Fahrettin Ay

# Sponsor: Dr. Moreira


# Figure 1. First responder crawls through smoke and broken glass to rescue elderly man from house fire (Independent TV)

# Problem: First Responders lack reliable methods for navigating dangerous environments, where visibility is limited, putting both their

safety and the victims at risk.

# Project Scope

# Our Solution: Building a Sound Localization robot that can hear distress calls, pinpoint their direction, and move toward them autonomously, allowing first responders to focus on saving lives

instead of risking theirs.

# •Keeps first responders safe by entering hazardous or toxic areas

first.

# •Reduces search and rescue time by avoiding exploring unnecessary paths •Reliable in low-visibility or high-

stress conditions (smoke, debris, noise).

# *A smarter, safer, and faster way to locate victims, all while

protecting rescuers and saving more lives.

# Robot Sub Systems:


# Input Signal Software

# Samuel Lackey

Accomplishments made since last presentation: | Ongoing plans for final Demonstration
- Found sound can still be detected with obstacles • Added a rough distance calculation | • Create a webapp to view live data from the ESP32

# Accomplishments made in 403:

# - TDOA algorithm working within 3.6° accuracy

# - Data outputs from mic Array and onto ESP32

# - Algorithm running on ESP 32

# Input Signal Software

# Samuel Lackey


# Figure 1. Calibration and filter constants

# Figure 2. Time Delay with Distance

# Figure 3. Subsystem Diagram

# Navigation Software Subsystem

# Lucas Kettler

Accomplishments made since last presentation: | Ongoing plans for final Demonstration:
- Ultrasonic sensor (HC-SR04) implementation, and algorithm testing in Wokwi simulation • Modification of Algorithm to handle edge cases | • Document multiple trials runs per simulation scenario • Perform the simulation test cases with the modified Algorithm using and the completed sound localization robot

# Accomplishments made in 403:

# - Implementation and testing of A* algorithm in C++ with a digital grid map - Added a map expansion function - Enabled use of a position shift function of goal and starting node in edge cases - Performed hardware simulations with sensor input

# Navigation Software

# Lucas Kettler


# Figure 2. Expanding grid map

# Figure 1. Simulated Sensor Input

# Figure 3. Wokwi Simulation

# Accomplishments made since last

presentation: | Ongoing plans for final Demonstration:

# - Soldered some permanent wiring connections - Debugged code and confirmed pins functionality and signals - Firmware and software validation for bidirectional, lateral, and stalling movement - Assembly of Chassis

# - Robot can take in user commands and execute without any errors - Maintain remote connection between ESP32 and user interface without any interruptions - Solder motor drivers & ESP32 together

# Mechanical/ Motor Controls Subsystem

# Sanjana Pasumarthi

# Accomplishments made in 403:

# - 3D printed robot chassis to physically hold components together - Soldered wiring connections for certain components - Programmed ESP32 to control motor drivers/ motors for movement - Built testbench to test the signals sent to motor drivers

Top View | Cross View PWM Test

# - Motors move in


# all 4 directions: Forward Backward, Left and Right - Wires need to be soldered for final demonstration

- PWM Frequency: 1 kHz,

# displayed from all 4 PWM pins at input of motor driver - Step Function: confirms ESP32 is generating on/off pulses not just some digital writes high/ low - Helped in Debugging to make sure GPIO functions & checks signal quality

# Testbench Signal Verification/ Software

# Mechanical/ Motor Controls Subsystem

# *Viewed input going into motor drivers matched expected bit control values

# Power & Distance Sensor Subsystem

# Joshua Teele

Accomplishments made since last presentation: | Ongoing plans for final presentation
- Performed line and load testing on buck converters that will be used for testing • Soldered system where battery can connect to converters and motors • Created test code for distance sensors | •Put together and test buck converters that I designed •Make the system that battery is connected to look nice and not be as fragile •Create small system with distance sensors

# Accomplishments made in 403:

# - Designed buck converters to be used to power components on the robot

# - Created code to run distance sensors

# Power & Distance Sensor Subsystem


# Joshua Teele

# Validation Plan

Test | Objective | Component Tested
Method | Pass Criteria

Ideal Path
Functionality

Verify shortest path
is taken | Navigation Loop

Run simulation with
no obstacles,
calculate
Manhattan
distance, visually
verify

Manhattan distance
path is taken by the
“robot”
Obstacle Detection | Detect obstacles within 9 inches on all sides | Sensor Software | Run a simulation with random ultrasonic sensor input for obstacles | On display obstacles are marked when sensors receive a distance < 9 inches
Obstacle Avoidance | Verify a halt to movement when encountering an obstacle | Motor Control | Run simulation and verify behavior after obstacle detection | The path in the simulation does not continue through an obstacle node
Path replanning | Verify that new path is made after obstacles found | Navigation Loop | After obstacle detection, calculate a new Manhattan distance | The new Manhattan distance path is taken by the “robot”
Expanding Grid map | Apply grid map expansion when given an out-of-bounds goal | Navigation Loop | Run simulation with goal node outside of original grid map | Grid map is expanded to be larger than that of goal node location
Negative direction movement | Handle movements in the [-X,-Y] region | Navigation Loop | Run a simulation with goal node in [-X,-Y] region | Goal node and starting node are shifted to be within bounds
Physical Hardware - I | Validate movement without obstacles | Navigation Software | Real world test environment with goal node hard coded | Goal reached with Manhattan distance path taken
Physical Hardware - II | Validate movement with obstacles/edge cases | Navigation Software | Real world test with physical obstacles in place | Goal reached for edge cases without making contact with obstacles
Test | Objective | Component
Tested
Method | Pass Criteria | ✓

Bidirectional
Motor Function

All motors shall
operate correctly in
both forward and
reverse directions

Motors, ESP32-S3,
Motor Drivers, All
subsystem wiring

All Motors move
forward and
backward at
constant speeds

Test PWM at driver
input, ± 5 % of
target frequency

✓

Lateral (Strafing) Motion Test | All motors shall coordinate to produce lateral (left and right) translation | Motors, ESP32-S3, Motor Drivers, all subsystem wiring | All Motors move laterally at constant speeds | Motors move backward, test PWM at driver input, ± 5 % of target frequency | ✓
Idle State Command Readiness | Remain in an idle state until a valid motion command is received | Motors, ESP32-S3, Motor Drivers | Robot stays in idle state, when no command is given | No PWM signal (0) at driver input | ✓
Wireless Connectivity & Stability | Maintain continuous and reliable communication between the ESP32 and the user interface | ESP32-S3 | Interface connected to ESP through Wifi or Bluetooth address | Robot connected to interface for at least 10 minutes without interruption
Remote Control Interface | Capable of receiving and executing control commands via both Bluetooth or Wi-Fi communication interfaces. | ESP32-S3 | Robot follows command given by user, and prompts response | Robot executes proper response to command
Firmware Integration and Execution | Firmware shall compile, upload, and execute without errors | ESP32-S3 | Create Testbench that prints signals sent to motor drivers for each function | Testbench displays proper bit values according to direction | ✓
Navigation Software Subsystem - Lucas | Motor Controls Subsystem - Sanjana

# Validation Plan

Test | Objective | Component

### Tested

Method | Pass Criteria | ✓
Input Voltage Range Test | Steady output voltage & current for range of input voltages (important range: 11-13V) | Buck converters (from FEDC cage) | Line regulation test using eload | Output voltages stay steady while pulling a constant current | ✓
Constant Output Voltage for Changing Load Current | Output voltage must stay constant if the output current changes (±5%) | Buck converters (from FEDC cage) | Load regulation test using eload | Output voltages stay steady while pulling a range of currents | ✓
Test Designed PCBs | PCBs output the voltages and currents designed for | Buck converters (designed by me) | Perform line and load regulation tests | Output needed voltages and currents
Simulate Distance Sensors | Distance sensors output a “stop” signal when detecting something within a small range (5 inches) | Ultrasonic Distance Sensors | Use online simulation software (tinkercad) to simulate code | Sensor outputs a signal which can be read to stop the car (lights up a red LED)
System wiring and powering | Create wiring system | All involved in wiring system | After putting together, test all system with all components connected | Everything is able to stay on

# Power & Distance Sensors Subsystem - Josh

Test | Objective | Component

### Tested

Method | Pass Criteria | ✓
I2S Data Integrity | Verify that non-static, valid audio data is being read from the I2S hardware. | UMA-8 Microphone Array ESP32 | Place a speaker playing a 1kHz tone then a 100Hz tone. | The 1kHz tone must produce a larger band energy. | ✓
DOA Angle Accuracy | Verify the angle calculation is accurate and repeatable for a known, static sound source | UMA-8 Microphone Array | Place speaker playing 1kHz tone at a known angle, and 1m distance. Run the detection test 5 times | All 5 tests must log a detected angle within an 3.6° | ✓
Distance Estimation | Verify the calibrated distance logic responds correctly to changes in distance | UMA-8 Microphone Array | Run the distance calibration software, move sound source from 0.5 to 1m to 2m. | The estimated distance must be less than 0.5m of the true distance | ✓
Webapp for output data | View live data from the algorithm via a wireless webapp | UMA-8 Microphone Array ESP32 | Run the program and connect to wifi, trigger a sound, and access the webapp | The webapp must show the angle, and estimated distance

# Input Signal Software - Sam

# Execution Plan


404 Continuation….

Samuel Lackey | Joshua Teele
- Improve TDOA to listen to periodic sounds • DOA should work with obstacles potentially blocking sound • Integrate ESP-32 software to navigation system and motor controls | • Create PCB to connect all components too • Integrate distance sensors into the main functionality of the robot
Lucas Kettler | Sanjana Pasumarthi
- Modify Navigation loop to reach out of sight goals given only a direction • Avoid unusually shaped obstacles/terrain | • Design & 3D print physical mounting poles that will hold microphone array in place • Integrate ESP32-S3 software with navigation & input signal system (take in input from other software)

# 404 Expectations and Mutual Understandings

# - Robot will move to sound source in & out of sight, and avoid obstacles

- Integrated WebApp with information portraying: location, angle, distance,

# current direction movement, alert user once destination is reached - Robot movement with periodical listening capability

Thank You,

# Any Questions?

# Sound Localization Robot 5 – Team 23

Samuel Lackey, Lucas Kettler, Joshua Teele,

# Sanjana Pasumarthi

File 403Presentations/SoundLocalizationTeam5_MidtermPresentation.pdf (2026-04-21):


# Sound Localization Robot, Team 5

# Samuel Lackey, Sanjana Pasumarthi, Lucas Kettler, Joshua Teele

# - Problem statement: First responders will often end up in situations where their vision and ability to navigate the scene become heavily obstructed


Figure 1. First responder crawls through smoke and broken glass to rescue elderly man from house fire (Independent TV)

# Solution proposal: - Develop a small robot that is can move in all four directions - Locate and Maneuver to sound source - Ignore background and machine noise - Alert when reaches sound source

# Robot Sub Systems:


# Input Signal Software

## Samuel Lackey


## Accomplishments since start: 20 Hours

## - Functioning test of microphone

## - Research of TDOA Algorithms

## Ongoing progress/problems and plans until the next presentation:

## - Lots of background noise

## - Mics are close, limits TDOA algorithm

# Navigation Software

## Lucas Kettler


## Accomplishments since start: 18 Hours

## - Full length pseudocode for simple pathing

## Ongoing progress/problems and plans until the next presentation:

## - Finished code ready for testing/debugging - Pseudocode for obstacle avoidance

# Mechanical/ Modeling Subsystem


# - Take in directions from the navigation system, and process it into instructions that the microcontroller can do - Takes in instructions from microcontroller to control the motors and steer wheels in direction of sound - Build funnel to amplify the sound that reaches the microphones

* Either ABS or PETG

# Power System and Distance Sensors


Power System | Joshua Teele

## - Subsystem powers every electrical component - Use of DC/DC buck converters to power low-power electronics - Switch near the source to turn robot on and off

## Distance Sensors System - System will be on every side of the chassis - Will be used to make sure robot does not run into anything

# Execution plan


# Validation plan

Test Name | Success Criteria | Methodology | Status | Engineer(s)
| | | | Responsible
Microphone Operating | Read analog audio from UMA-8 Mic Array | A 440Hz sound is played from differing locations and distances from the mic.
| | Volume and some direction will be seen using a Python Script | Success | Sam Lackey
Funnel Operation | Amplify sound reaching microphone | Use software to see sound arcs reaching microphone, then 3D-print to test on
| | actual microphone array | Untested | Sanjana
| | | | Pasumarthi
Test Motor Direction | Wheels can move in all 4 directions | Take in instructions from microcontroller, and make sure the circuit works | Untested | Sanjana
| | | | Pasumarthi
Battery Charge | Battery charges and decharges | Charge and uncharge while measuring current and voltage compared to spec sheet | Untested | Joshua Teele

Power System Test

With the system under a simulated full load, all regulated voltage outputs (e.g., 3.3V, 5V, 12V) must remain stable and within ±5% of their target values.

Using a multimeter and power resistors to simulate load, measure the voltage at
each regulator's output on the PCB. Verify stability and accuracy against the design
| | specifications. | Untested | Joshua Teele
Motor Control | Motor spins at a set RPM | Motor is connected to a simple controller and powered on | Untested | Lucas Kettler
Distance Sensor | Sensor detects a wall ~6 inches away | Sensor is connected to a simple independent circuit, and brought to a measured
| | distance from a wall | Untested | Joshua Teele
Final Audio Processing | Sound angle can be detected within 3
| degrees | Play a 440Hz sound at different predetermined angles around the microphone
| | array, compared final output to tested angle | Untested | Samuel Lackey
Final Motor Drive | When given a target angle, motors must
| complete turn in correct direction | Using a test firmware, send a specific angle command to the robot. Motors will
| | perform turn and visually verify the accuracy of the turn against a marked surface. | Untested | Lucas Kettler

Final Power Test

With the system under a full load, all
regulated voltage outputs (5V, 12V) must remain stable and within ±5% of their target values.

Connect an oscilloscope to microcontrollers, motors, and microphone array, and
test motor actions with microcontroller acting. Measure voltage and current to
ensure battery is powering the whole system. | Untested | Joshua Teele

Final Motor Control Signal Verification

When a navigation command is given the correct GPIO pins on the microcontroller must output the corresponding direction signal

Connect an oscilloscope to output pins of microcontroller, send commands, and

verify the correct output | Untested | Sanjana
| | Pasumarthi

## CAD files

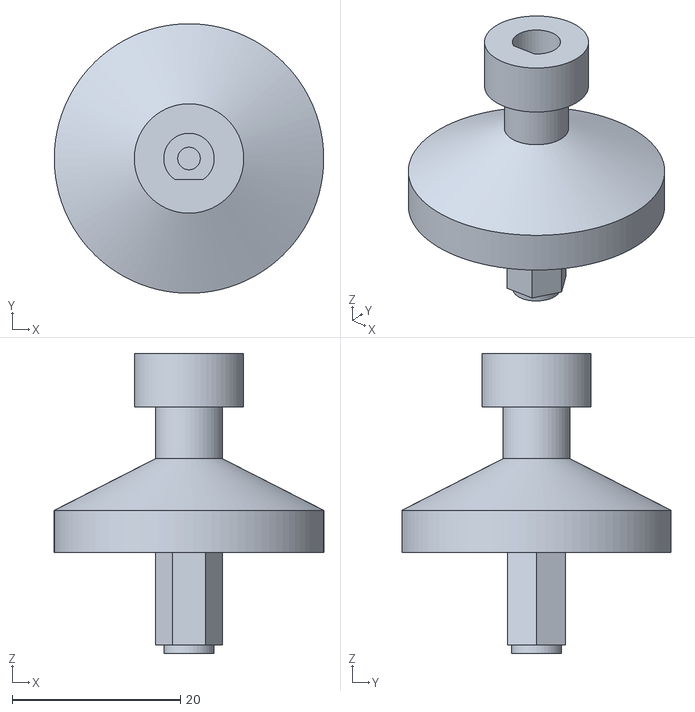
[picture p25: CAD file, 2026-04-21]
3DFiles/Wheel_shaft_actual_final.stl
32.0 x 32.0 x 35.6

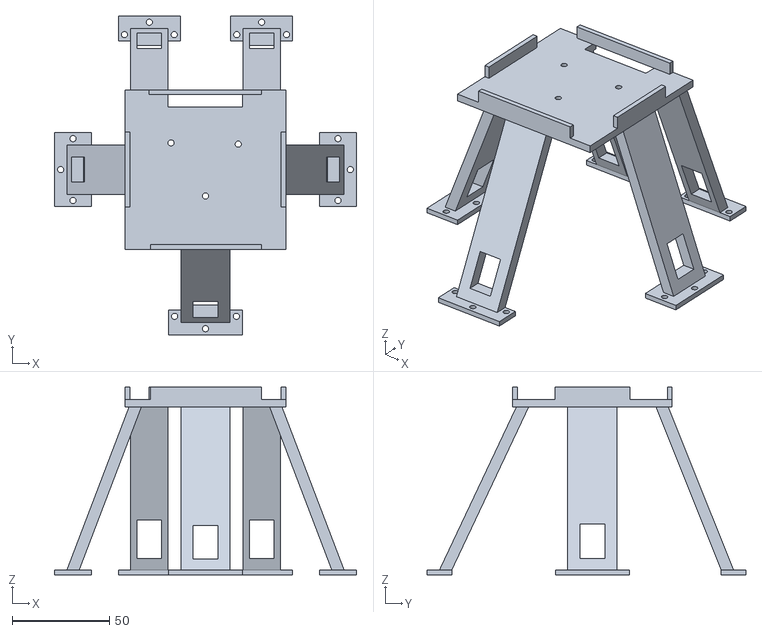
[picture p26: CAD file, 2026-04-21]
3DFiles/stand_layer_reprint.stl
155.2 x 163.8 x 96.5

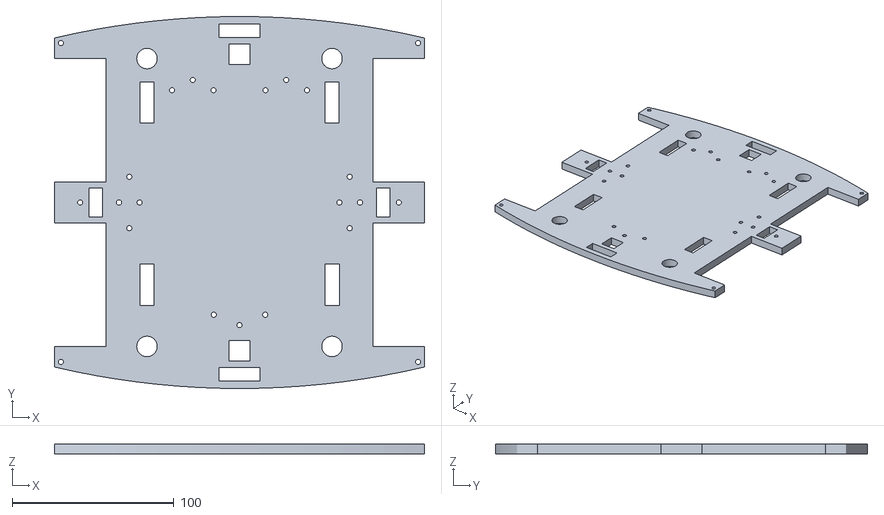
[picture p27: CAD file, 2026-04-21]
3DFiles/Top_layer_base.stl
228.6 x 229.8 x 6.35

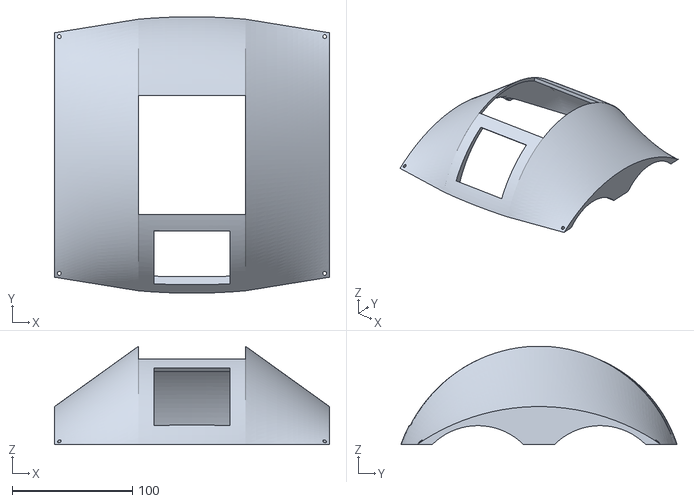
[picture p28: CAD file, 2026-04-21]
3DFiles/Final_casing.stl
228.6 x 229.7 x 81.9

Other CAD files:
3DFiles/final_base_layer_reprint.stl

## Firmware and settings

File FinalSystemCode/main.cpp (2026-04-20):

// =============================================================================
//  SOUND ROVER - FULLY INTEGRATED FIRMWARE
//  ESP32-S3 Wroom | ESP-IDF Framework | PlatformIO
// =============================================================================
//  Combines:
//    - 4-Mic Phase-Gradient TDOA Sound Localization
//    - Mecanum Wheel Navigation with A* Path Planning
//    - Obstacle Detection via 4x Ultrasonic Sensors
//    - WiFi Access Point + Web UI (map, status, manual control)
//
//  Architecture (FreeRTOS Tasks):
//    Core 0: WiFi/HTTP server  +  sound_task (I2S + DSP)
//    Core 1: nav_task (A* + motor control)
//
//  Shared state (protected by mutex):
//    g_sound_angle    - latest detected sound angle (degrees, 0=North/forward)
//    g_sound_distance - estimated distance to sound source (meters)
//    g_sound_valid    - true when a confident detection exists
//    g_sound_updated  - flag: nav_task consumes this to trigger navigation
//
//  Behaviour:
//    - Continuous sound listening; drives ONLY when "Chase Sound Source" is
//      clicked in the web UI (g_chase_requested flag).  The robot will NOT
//      autonomously start chasing sound on its own.
//    - If quiet: keeps listening, does NOT drive
//    - "Re-check every N steps" pauses mid-route, re-listens, re-plans if
//      heading changed > RECHECK_ANGLE_DELTA degrees
//    - Arrival detected by: magnitude >= ARRIVAL_MAG_FACTOR * start_magnitude
//      AND an obstacle within ARRIVAL_OBST_CM in the current travel direction.
//      This is far more reliable than inverse-square distance estimation.
//    - Manual start via web UI (direction + distance) still fully works
//    - Emergency stop from web UI halts both sound and nav
//
// =============================================================================

#include <stdio.h>  
#include <stdlib.h>  
#include <string.h>  
#include <math.h>  
#include <algorithm>  
#include <vector>  
#include <queue>  
#include <tuple>  
#include <complex>  
 
#include "freertos/FreeRTOS.h"  
#include "freertos/task.h"  
#include "freertos/event_groups.h"  
#include "freertos/semphr.h"  
 
#include "esp_system.h"  
#include "esp_log.h"  
#include "esp_wifi.h"  
#include "esp_event.h"  
#include "esp_timer.h"  
#include "esp_rom_sys.h"  
#include "nvs_flash.h"  
 
#include "driver/gpio.h"  
#include "driver/ledc.h"  
#include "driver/i2s_std.h"  
 
#include "esp_http_server.h"  
 
using std::vector;  
using std::min;  
using std::max;  
using Complex = std::complex<float>;  
 
static const char* TAG = "SoundRover";  
 
// =============================================================================  
//  SOUND LOCALIZATION - CONFIGURATION  
// =============================================================================  
#define I2S_BCK_IO          GPIO_NUM_40  
#define I2S_WS_IO           GPIO_NUM_39  
#define I2S_DO_0_IO         GPIO_NUM_41   // I2S0 Data In (Mics 0 & 1)  
#define I2S_DO_1_IO         GPIO_NUM_42   // I2S1 Data In (Mics 2 & 3)  
 
#define SAMPLE_RATE         24000  
#define FFT_SIZE            1024  
#define BUFF_SIZE           FFT_SIZE  
#define SPEED_OF_SOUND      343.0f  
 
#define TARGET_FREQ         1000.0f       // Hz — beacon frequency to track
#define TARGET_SIGMA        5.0f          // Hz — Gaussian filter bandwidth
#define SMOOTHING           0.90f         // Temporal smoothing factor (0-1)
#define MAG_THRESHOLD       150000.0f     // Min FFT magnitude to consider valid
#define ANGLE_STEP          2             // Degrees per beamforming scan step

// Distance estimation via inverse-square law (used only as fallback for
// initial nav goal sizing; arrival is NOT determined by this value).
#define REFERENCE_ENERGY    0.05f
#define REFERENCE_DISTANCE  0.05f         // meters at reference energy
 
// ---------------------------------------------------------------------------  
//  ARRIVAL DETECTION  
//  
//  Arrival is declared purely by FFT magnitude growth — no ultrasonic check.  
//  This avoids false arrivals caused by ordinary walls or furniture, which  
//  would previously satisfy an "obstacle in front" condition.  
//  Normal obstacle avoidance (OBST_THRESH_CM) continues to work as usual for  
//  both manual and sound-chase navigation — arrival logic never interferes.  
//  
//  ARRIVAL_MAG_FACTOR: current magnitude must be >= start_mag * this value.  
//    Lower  = robot stops earlier (less magnitude growth required).  
//    Higher = robot must get much closer before stopping.  
//  
//  ARRIVAL_MIN_STEPS: robot must have taken at least this many steps before  
//    arrival can trigger.  Prevents a false stop on the very first frame  
//    if the room is reflective or the source is already loud.  
//  
//  SOUND_MIN_DISTANCE_IN: minimum initial goal distance in inches regardless  
//    of what the inverse-square energy estimator returns.  
// ---------------------------------------------------------------------------  
#define ARRIVAL_MAG_FACTOR      4.0f   // arrival mag must be >= N * start mag  
#define ARRIVAL_MIN_STEPS       3     // don't check arrival for first N steps  
#define SOUND_MIN_DISTANCE_IN   60.0f // minimum goal distance in inches
 
// Legacy — no longer used for arrival; kept so old references compile cleanly.  
#define SOUND_CLOSE_DIST    0.4f  
#define ARRIVAL_OBST_CM     50.0f  

// =============================================================================  
//  NAVIGATION RE-CHECK CONFIGURATION  
// =============================================================================  
#define RECHECK_INTERVAL    5       // steps between sound rechecks (0 = off)  
#define RECHECK_LISTEN_MS   500     // ms to listen during a recheck — 4-5 FFT
                                    // frames at 104ms each is enough for the
                                    // beamformer smoother (alpha=0.85) to settle
#define RECHECK_ANGLE_DELTA 15.0f   // degrees change needed to trigger re-plan  
 
// =============================================================================  
//  LED  
// =============================================================================  
#define RED_LED_PIN GPIO_NUM_38  
 
void setLED(bool on) { gpio_set_level(RED_LED_PIN, on ? 1 : 0); }  
 
void flashLED(int duration_ms = 120) {  
    gpio_set_level(RED_LED_PIN, 1);  
    vTaskDelay(pdMS_TO_TICKS(duration_ms));  
    gpio_set_level(RED_LED_PIN, 0);  
}  
 
void initLED() {  
    gpio_config_t cfg = {};  
    cfg.pin_bit_mask  = (1ULL << RED_LED_PIN);  
    cfg.mode          = GPIO_MODE_OUTPUT;  
    cfg.pull_up_en    = GPIO_PULLUP_DISABLE;  
    cfg.pull_down_en  = GPIO_PULLDOWN_DISABLE;  
    cfg.intr_type     = GPIO_INTR_DISABLE;  
    gpio_config(&cfg);  
    gpio_set_level(RED_LED_PIN, 0);  
}  
 
// =============================================================================  
//  ULTRASONIC SENSORS  
//  
//  OBST_THRESH_CM  — change this single value to adjust detection distance.  
//  15 inches = 38.1 cm  |  12 inches = 30.5 cm  |  24 inches = 61.0 cm  
//  
//  Uses GPIO edge interrupts + FreeRTOS semaphore instead of a busy-wait loop,  
//  so the CPU is properly yielded while waiting for the echo pulse.  
// =============================================================================  
#define OBST_THRESH_CM      25.4f    // cm — distance considered "blocked"  
#define US_SOUND_CM_PER_US  0.01715f // cm/us  (343 m/s / 2 for round-trip)  
#define US_TIMEOUT_US       25000    // 25 ms max wait -> ~4.3 m max range  
#define US_STABLE_READINGS  3        // readings averaged per measurement  
 
#define TRIG_LEFT   GPIO_NUM_1  
#define ECHO_LEFT   GPIO_NUM_2  
#define TRIG_BACKL   GPIO_NUM_4
#define ECHO_BACKL   GPIO_NUM_5  
#define TRIG_RIGHT  GPIO_NUM_10  
#define ECHO_RIGHT  GPIO_NUM_11  
#define TRIG_FRONTL  GPIO_NUM_36  
#define ECHO_FRONTL  GPIO_NUM_37  
#define TRIG_FRONTR GPIO_NUM_12
#define ECHO_FRONTR GPIO_NUM_35
#define TRIG_BACKR  GPIO_NUM_9
#define ECHO_BACKR  GPIO_NUM_16
 
// Per-sensor ISR state — each sensor has its own semaphore and rise/fall  
// timestamps so they can never corrupt each other's measurement.  
struct USSensor {  
    gpio_num_t        trig;  
    gpio_num_t        echo;  
    volatile int64_t  rise;  
    volatile int64_t  fall;  
    volatile bool     done;  
    SemaphoreHandle_t sem;  
};  
 
// Sensor table — index matches ECHO pin lookup in echo_isr via linear scan.  
// Declared before ISR so the ISR can find the right entry by echo pin number.  
static USSensor s_sensors[6]; // filled in initUltrasonicISR()  
 
static void IRAM_ATTR echo_isr(void* arg) {  
    gpio_num_t pin = (gpio_num_t)(intptr_t)arg;  
    // Find the matching sensor entry by echo pin  
    for (int i = 0; i < 6; i++) {  
        if (s_sensors[i].echo == pin) {  
            if (gpio_get_level(pin)) {  
                s_sensors[i].rise = esp_timer_get_time();  
            } else {  
                s_sensors[i].fall = esp_timer_get_time();  
                s_sensors[i].done = true;  
                BaseType_t woken = pdFALSE;  
                xSemaphoreGiveFromISR(s_sensors[i].sem, &woken);  
                portYIELD_FROM_ISR(woken);  
            }  
            return;  
        }  
    }  
}  
 
void initUltrasonicPins() {  
    gpio_num_t trigs[] = { TRIG_LEFT, TRIG_BACKL, TRIG_RIGHT, TRIG_FRONTL, TRIG_FRONTR, TRIG_BACKR };  
    for (gpio_num_t pin : trigs) {  
        gpio_config_t cfg = {};  
        cfg.pin_bit_mask = (1ULL << pin);  
        cfg.mode         = GPIO_MODE_OUTPUT;  
        cfg.pull_up_en   = GPIO_PULLUP_DISABLE;  
        cfg.pull_down_en = GPIO_PULLDOWN_DISABLE;  
        cfg.intr_type    = GPIO_INTR_DISABLE;  
        gpio_config(&cfg);  
        gpio_set_level(pin, 0);  
    }  
    gpio_num_t echos[] = { ECHO_LEFT, ECHO_BACKL, ECHO_RIGHT, ECHO_FRONTL, ECHO_FRONTR, ECHO_BACKR };  
    for (gpio_num_t pin : echos) {  
        gpio_config_t cfg = {};  
        cfg.pin_bit_mask = (1ULL << pin);  
        cfg.mode         = GPIO_MODE_INPUT;  
        cfg.pull_up_en   = GPIO_PULLUP_DISABLE;  
        cfg.pull_down_en = GPIO_PULLDOWN_DISABLE;  
        cfg.intr_type    = GPIO_INTR_DISABLE;  
        gpio_config(&cfg);  
    }  
}  
 
void initUltrasonicISR() {  
    // Build per-sensor table  
    gpio_num_t trigs[] = { TRIG_LEFT, TRIG_BACKL, TRIG_RIGHT, TRIG_FRONTL, TRIG_FRONTR, TRIG_BACKR };  
    gpio_num_t echos[] = { ECHO_LEFT, ECHO_BACKL, ECHO_RIGHT, ECHO_FRONTL, ECHO_FRONTR, ECHO_BACKR };  
    for (int i = 0; i < 6; i++) {  
        s_sensors[i].trig = trigs[i];  
        s_sensors[i].echo = echos[i];  
        s_sensors[i].rise = 0;  
        s_sensors[i].fall = 0;  
        s_sensors[i].done = false;  
        s_sensors[i].sem  = xSemaphoreCreateBinary();  
    }  
 
    ESP_ERROR_CHECK(gpio_install_isr_service(0));  
    for (int i = 0; i < 6; i++) {  
        ESP_ERROR_CHECK(gpio_set_intr_type(echos[i], GPIO_INTR_ANYEDGE));  
        ESP_ERROR_CHECK(gpio_isr_handler_add(echos[i], echo_isr, (void*)(intptr_t)echos[i]));  
    }  
    ESP_LOGI(TAG, "Ultrasonic ISR installed (per-sensor, 6 sensors) — threshold %.1f cm (%.1f in)",  
             OBST_THRESH_CM, OBST_THRESH_CM / 2.54f);  
}  
 
// Returns the USSensor entry for a given echo pin, or nullptr if not found.  
static USSensor* sensorByEcho(gpio_num_t echopin) {  
    for (int i = 0; i < 6; i++)  
        if (s_sensors[i].echo == echopin) return &s_sensors[i];  
    return nullptr;  
}  
 
static float distanceCm(gpio_num_t trigpin, gpio_num_t echopin) {  
    USSensor* s = sensorByEcho(echopin);  
    if (!s) return 999.0f;  
 
    // Drain any stale token from a previous trigger  
    xSemaphoreTake(s->sem, 0);  
    s->done = false;  
    s->rise = 0;  
    s->fall = 0;  
 
    gpio_set_level(trigpin, 0); esp_rom_delay_us(2);  
    gpio_set_level(trigpin, 1); esp_rom_delay_us(10);  
    gpio_set_level(trigpin, 0);  
 
    if (xSemaphoreTake(s->sem, pdMS_TO_TICKS(35)) != pdTRUE) {  
        return 999.0f;  
    }  
    if (!s->done || s->fall <= s->rise) return 999.0f;  
 
    int64_t duration_us = s->fall - s->rise;  
    if (duration_us > US_TIMEOUT_US) return 999.0f;  
 
    return (float)duration_us * US_SOUND_CM_PER_US;  
}  
 
float getStableDistance(gpio_num_t trigpin, gpio_num_t echopin) {  
    float sum   = 0.0f;  
    int   valid = 0;  
    for (int i = 0; i < US_STABLE_READINGS; i++) {  
        float d = distanceCm(trigpin, echopin);  
        if (d < 999.0f) { sum += d; valid++; }  
        vTaskDelay(pdMS_TO_TICKS(10));  
    }  
    if (valid == 0) return 999.0f;  
    float avg = sum / (float)valid;  
    return (avg < 2.0f) ? 999.0f : avg;  
}  
 
// =============================================================================  
//  MOTOR PINS & LEDC  
// =============================================================================  
#define MF_PWMA  GPIO_NUM_45  
#define MF_AI1   GPIO_NUM_47  
#define MF_AI2   GPIO_NUM_48  
#define MF_PWMB  GPIO_NUM_13  
#define MF_BI1   GPIO_NUM_21  
#define MF_BI2   GPIO_NUM_14  
#define MR_PWMA  GPIO_NUM_8  
#define MR_AI1   GPIO_NUM_6  
#define MR_AI2   GPIO_NUM_7  
#define MR_PWMB  GPIO_NUM_18  
#define MR_BI1   GPIO_NUM_15  
#define MR_BI2   GPIO_NUM_17  
 
#define LEDC_FREQ_HZ    1000  //pwm
#define LEDC_RESOLUTION LEDC_TIMER_8_BIT  
 
#define LEDC_TIMER_RF   LEDC_TIMER_0  
#define LEDC_TIMER_LF   LEDC_TIMER_1  
#define LEDC_TIMER_RR   LEDC_TIMER_2  
#define LEDC_TIMER_LR   LEDC_TIMER_3  
#define LEDC_CH_RF      LEDC_CHANNEL_0  
#define LEDC_CH_LF      LEDC_CHANNEL_1  
#define LEDC_CH_RR      LEDC_CHANNEL_2  
#define LEDC_CH_LR      LEDC_CHANNEL_3  
 
void initMotorPWM() {  
    ledc_timer_config_t tc = {};  
    tc.speed_mode      = LEDC_LOW_SPEED_MODE;  
    tc.duty_resolution = LEDC_RESOLUTION;  
    tc.freq_hz         = LEDC_FREQ_HZ;  
    tc.clk_cfg         = LEDC_AUTO_CLK;  
    tc.timer_num = LEDC_TIMER_RF; ledc_timer_config(&tc);  
    tc.timer_num = LEDC_TIMER_LF; ledc_timer_config(&tc);  
    tc.timer_num = LEDC_TIMER_RR; ledc_timer_config(&tc);  
    tc.timer_num = LEDC_TIMER_LR; ledc_timer_config(&tc);  
 
    ledc_channel_config_t ch = {};  
    ch.speed_mode = LEDC_LOW_SPEED_MODE;  
    ch.intr_type  = LEDC_INTR_DISABLE;  
    ch.duty = 0; ch.hpoint = 0;  
    ch.channel = LEDC_CH_RF; ch.gpio_num = MF_PWMA; ch.timer_sel = LEDC_TIMER_RF; ledc_channel_config(&ch);  
    ch.channel = LEDC_CH_LF; ch.gpio_num = MF_PWMB; ch.timer_sel = LEDC_TIMER_LF; ledc_channel_config(&ch);  
    ch.channel = LEDC_CH_RR; ch.gpio_num = MR_PWMA; ch.timer_sel = LEDC_TIMER_RR; ledc_channel_config(&ch);  
    ch.channel = LEDC_CH_LR; ch.gpio_num = MR_PWMB; ch.timer_sel = LEDC_TIMER_LR; ledc_channel_config(&ch);  
}  
 
void setMotorPWM(ledc_channel_t ch, int duty) {  
    ledc_set_duty(LEDC_LOW_SPEED_MODE, ch, (uint32_t)abs(duty));  
    ledc_update_duty(LEDC_LOW_SPEED_MODE, ch);  
}  
 
void initMotorGPIO() {  
    gpio_num_t pins[] = { MF_AI1, MF_AI2, MF_BI1, MF_BI2,  
                          MR_AI1, MR_AI2, MR_BI1, MR_BI2 };  
    for (gpio_num_t pin : pins) {  
        gpio_config_t cfg = {};  
        cfg.pin_bit_mask = (1ULL << pin);  
        cfg.mode         = GPIO_MODE_OUTPUT;  
        cfg.pull_up_en   = GPIO_PULLUP_DISABLE;  
        cfg.pull_down_en = GPIO_PULLDOWN_DISABLE;  
        cfg.intr_type    = GPIO_INTR_DISABLE;  
        gpio_config(&cfg);  
        gpio_set_level(pin, 0);  
    }  
}  
 
// =============================================================================  
//  MECANUM DIRECTION BYTES  
// =============================================================================  
const uint8_t MEC_STRAIGHT_FORWARD  = 0b01100110;  
const uint8_t MEC_STRAIGHT_BACKWARD = 0b10011001;  
const uint8_t MEC_SIDEWAYS_LEFT     = 0b01011010; 
const uint8_t MEC_SIDEWAYS_RIGHT    = 0b10100101;  
 
// =============================================================================  
//  NAVIGATION GLOBALS  
// =============================================================================  
const int MAX_GRID  = 60;  
const int EXPAND_BY = 10;  
const int MAX_STEPS = 300;  
 
vector<vector<int>> grid;  
vector<std::pair<int,int>> visited;  
int curX = 0, curY = 0, goalX = 0, goalY = 0;
int origStartX = -1, origStartY = -1;
int  currentStep       = 0;  
bool navigationActive  = false;  
bool emergencyStop     = false;  
bool soundNavMode      = false;  
// FIX 1: g_orig_start_set ensures origStartX/Y is only written once per
// fresh navigation session, never overwritten by mid-run replans or rechecks.
bool g_orig_start_set  = false;
char statusMessage[256] = "Idle — press Chase Sound Source to begin.";  
 
// Timer state
static int64_t g_nav_start_time = 0;
static int64_t g_nav_elapsed_us = 0;

// FIX 2: Total grid steps traveled; each step = 9 in.
// Reset only on a genuine fresh start, not on replans.
static int g_total_steps_traveled = 0;

// Displacement Tracking (Immune to grid shifts)
// Represents net steps taken since the true start.
static int g_net_dx = 0;
static int g_net_dy = 0;

// Strafe PWM values configured via web UI (defaults requested by user)
int g_pwm_left_rf=229,  g_pwm_left_lf=235,  g_pwm_left_rr=237,  g_pwm_left_lr=230;
int g_pwm_right_rf=230, g_pwm_right_lf=240, g_pwm_right_rr=240, g_pwm_right_lr=230;

// Current travel direction (updated each step; used for arrival obstacle check)  
static char g_current_dir[16] = "forward";  
 
// =============================================================================  
//  SHARED SOUND STATE  (mutex-protected, written by sound_task)  
// =============================================================================  
static SemaphoreHandle_t g_sound_mutex = NULL;  
static float g_sound_angle    = 0.0f;  
static float g_sound_distance = -1.0f;  
static bool  g_sound_valid    = false;  
static bool  g_sound_updated  = false;  
static float g_sound_rms[4]   = {};  
static float g_sound_mag      = 0.0f;   // latest average magnitude at peak  
 
// Magnitude snapshot taken when Chase Sound Source is clicked.  
// Arrival check compares live magnitude against this baseline.  
static float g_chase_start_mag = 0.0f;  
 
// Set by handler_sound_start (web button); consumed by nav_task.  
// nav_task NEVER self-starts — it waits for this flag.  
static bool  g_chase_requested = false;  
 
// I2S handles  
static i2s_chan_handle_t rx_handle_0 = NULL;  
static i2s_chan_handle_t rx_handle_1 = NULL;  
 
// =============================================================================  
//  DSP GLOBALS  
// =============================================================================  
static const float PI_F = 3.14159265358979323846f;
static int g_recheck_interval = RECHECK_INTERVAL;

// Runtime-configurable target frequency (default = compile-time TARGET_FREQ).
// Changing this via /set_freq rebuilds DSP tables and restarts the scan band.
static float g_target_freq = TARGET_FREQ;

// Runtime-configurable move durations (ms).
// Forward/backward and side-to-side can use different values.
#define MOVE_DELAY_FWD_MS   235   // default for forward / backward
#define MOVE_DELAY_SIDE_MS  235   // default for left / right (strafe)
static int g_move_delay_fwd_ms  = MOVE_DELAY_FWD_MS;
static int g_move_delay_side_ms = MOVE_DELAY_SIDE_MS;

// Absolute physical start — recorded ONCE per fresh session (never shifted).
// Unlike origStartX/Y (which live in grid coordinates and move when the grid
// expands/shifts), these store the robot's real-world step-count offsets from
// the session origin so the return path targets the exact launch point.
// We track it as cumulative (dx, dy) steps from the true first position.
static int g_abs_start_grid_x = -1;
static int g_abs_start_grid_y = -1;
static bool g_abs_start_valid = false;

// =============================================================================
//  MIC GEOMETRY  (SRP-PHAT beamformer)
//  0,0 is center of the array. +Y = forward (front of rover), +X = right.
//  0 deg = forward (+Y), 90 deg = right (+X)  — navigation coordinates.
// =============================================================================
struct Point { float x, y; };

const Point MIC_POSITIONS[4] = {
    { 0.03175f, 0.03175f },   // Mic 0
    { 0.03175f,  -0.03175f },   // Mic 1
    { -0.03175f, 0.03175f },  // Mic 2
    { -0.03175f,  -0.03175f },  // Mic 3
};

// Precomputed SRP-PHAT steering vectors and gaussian frequency weights
static vector<vector<Complex>> s_steering_vectors;
static vector<Complex>         s_smoothed_bins(4, Complex(0.0f, 0.0f));
static vector<float>           s_gaussian_weights;
static float                   g_last_valid_angle = 0.0f;
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
extern "C" void app_main() {
    // Initialize NVS (required for WiFi Access Point)
    esp_err_t ret = nvs_flash_init();
    if (ret == ESP_ERR_NVS_NO_FREE_PAGES || ret == ESP_ERR_NVS_NEW_VERSION_FOUND) {
        ESP_ERROR_CHECK(nvs_flash_erase());
        ret = nvs_flash_init();
    }
    ESP_ERROR_CHECK(ret);

    printf("\n========================================\n");
    printf("       SOUND ROVER INITIALIZING\n");
    printf("========================================\n\n");

    // Initialize Shared Mutex
    g_sound_mutex = xSemaphoreCreateMutex();

    // Initialize Hardware
    initLED();
    initMotorGPIO();
    initMotorPWM();
    initUltrasonicPins();
    initUltrasonicISR();

    // Initialize DSP & Microphones
    precompute_dsp();
    init_microphone_i2s();

    // Start Network & UI
    setupAP();
    start_webserver();

    // Launch Tasks
    // Core 0: WiFi / HTTP Server (handled by ESP-IDF internally) + Sound Processing
    xTaskCreatePinnedToCore(sound_task, "sound_task", 8192, NULL, 5, NULL, 0);

    // Core 1: Navigation, Path Planning, & Motor Control
    xTaskCreatePinnedToCore(nav_task, "nav_task", 8192, NULL, 5, NULL, 1);

    printf("\nSystem initialized! Connect to 'Sound_Rover' WiFi and go to http://192.168.4.1\n");
}

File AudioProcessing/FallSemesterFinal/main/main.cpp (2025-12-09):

#include <stdio.h>
#include <string.h>
#include <math.h>
#include <vector>
#include <complex>
#include <algorithm>
#include <set>
#include <mutex>

#include "freertos/FreeRTOS.h"
#include "freertos/task.h"
#include "driver/i2s_std.h"
#include "driver/gpio.h"
#include "esp_log.h"
#include "esp_wifi.h"
#include "esp_event.h"
#include "nvs_flash.h"
#include "esp_http_server.h"
#include "cJSON.h"
#include "lwip/err.h"
#include "lwip/sys.h"

// --- WIFI CONFIGURATION ---
#define WIFI_SSID      "SamiPhone"  
#define WIFI_PASS      "password" 

// --- SERVER CONFIGURATION ---
#define SERVER_PORT     9003
#define STATUS_LED_GPIO GPIO_NUM_2 

// --- PIN CONFIGURATION ---
#define I2S_BCK_IO      GPIO_NUM_42
#define I2S_WS_IO       GPIO_NUM_41
#define I2S_DO_0_IO     GPIO_NUM_16 // I2S0 Data In
#define I2S_DO_1_IO     GPIO_NUM_40 // I2S1 Data In

// --- AUDIO CONFIGURATION ---
#define SAMPLE_RATE     16000
#define FFT_SIZE        1024        
#define BUFF_SIZE       FFT_SIZE
#define SPEED_OF_SOUND  343.0f

// --- ALGORITHM TUNING ---
#define TARGET_FREQ     450.0f      
// Tighter Sigma = Stricter Filter. 5.0f means it ignores 430hz or 470hz.
#define TARGET_SIGMA    5.0f        
#define SMOOTHING       0.85f       
#define MAG_THRESHOLD   200000.0f    
#define ANGLE_STEP      2           // Scans every 2 degrees for higher precision

// --- DISTANCE ESTIMATION CONSTANTS ---
const float REFERENCE_ENERGY = 0.05f;
const float REFERENCE_DISTANCE = 0.05f;

// --- MIC GEOMETRY ---
// 0,0 is the center of the square.
// +Y is "North" (Top), +X is "East" (Right)
struct Point { float x, y; };

const Point MIC_POSITIONS[4] = {
    // Mic 0: Bottom Right (+X, -Y)
    { -0.0381f, -0.0254f}, 
    // Mic 1: Bottom Left  (-X, -Y)
    {-0.0381f, 0.0254f}, 
    // Mic 2: Top Left     (-X, +Y)
    {0.0381f,  -0.0254f}, 
    // Mic 3: Top Right    (+X, +Y)
    { 0.0381f,  0.0254f}  
};

// --- GLOBALS ---
static i2s_chan_handle_t rx_handle_0 = NULL;
static i2s_chan_handle_t rx_handle_1 = NULL;
static const char *TAG = "TDOA_FIX";

const float PI = 3.14159265358979323846f;
using Complex = std::complex<float>;

// DSP Globals
std::vector<std::vector<Complex>> steering_vectors; 
std::vector<Complex> smoothed_bins(4, Complex(0,0));
std::vector<float> gaussian_weights; //used to filter the 450Hz signal

// WebServer Globals
static httpd_handle_t server = NULL;
std::set<int> g_client_sockets;
std::mutex g_client_mutex;
volatile bool g_wifi_connected = false;

float g_last_valid_angle = 0.0f; // Stores last valid angle for persistence

// --- WIFI HANDLERS ---
static void wifi_event_handler(void* arg, esp_event_base_t event_base,
                               int32_t event_id, void* event_data) {
    if (event_base == WIFI_EVENT && event_id == WIFI_EVENT_STA_START) {
        esp_wifi_connect();
    } else if (event_base == WIFI_EVENT && event_id == WIFI_EVENT_STA_DISCONNECTED) {
        g_wifi_connected = false;
        gpio_set_level(STATUS_LED_GPIO, 0);
        esp_wifi_connect();
    } else if (event_base == IP_EVENT && event_id == IP_EVENT_STA_GOT_IP) {
        ip_event_got_ip_t* event = (ip_event_got_ip_t*) event_data;
        ESP_LOGI(TAG, "IP: " IPSTR, IP2STR(&event->ip_info.ip));
        ESP_LOGI(TAG, "Use this IP in your browser: http://" IPSTR ":9003", IP2STR(&event->ip_info.ip));
        g_wifi_connected = true;
        gpio_set_level(STATUS_LED_GPIO, 1);
    }
}

void wifi_init_sta(void) {
    nvs_flash_init();
    esp_netif_init();
    esp_event_loop_create_default();
    esp_netif_create_default_wifi_sta();
    wifi_init_config_t cfg = WIFI_INIT_CONFIG_DEFAULT();
    esp_wifi_init(&cfg);
    esp_event_handler_instance_register(WIFI_EVENT, ESP_EVENT_ANY_ID, &wifi_event_handler, NULL, NULL);
    esp_event_handler_instance_register(IP_EVENT, IP_EVENT_STA_GOT_IP, &wifi_event_handler, NULL, NULL);
    wifi_config_t wifi_config = {};
    strcpy((char*)wifi_config.sta.ssid, WIFI_SSID);
    strcpy((char*)wifi_config.sta.password, WIFI_PASS);
    wifi_config.sta.threshold.authmode = WIFI_AUTH_WPA2_PSK;
    esp_wifi_set_mode(WIFI_MODE_STA);
    esp_wifi_set_config(WIFI_IF_STA, &wifi_config);
    esp_wifi_start();
}

// --- WEBSOCKET HANDLERS ---
static esp_err_t ws_handler(httpd_req_t *req) {
    if (req->method == HTTP_GET) {
        int sockfd = httpd_req_to_sockfd(req);
        std::lock_guard<std::mutex> lock(g_client_mutex);
        g_client_sockets.insert(sockfd);
        return ESP_OK;
    }
    httpd_ws_frame_t ws_pkt;
    memset(&ws_pkt, 0, sizeof(httpd_ws_frame_t));
    esp_err_t ret = httpd_ws_recv_frame(req, &ws_pkt, 0);
    if (ret != ESP_OK) return ret;
    if (ws_pkt.type == HTTPD_WS_TYPE_CLOSE) {
        int sockfd = httpd_req_to_sockfd(req);
        std::lock_guard<std::mutex> lock(g_client_mutex);
        g_client_sockets.erase(sockfd);
        return ESP_OK;
    }
    return ESP_OK;
}

static const httpd_uri_t ws_route = {
    .uri        = "/",
    .method     = HTTP_GET,
    .handler    = ws_handler,
    .user_ctx   = NULL,
    .is_websocket = true
};

void start_webserver(void) {
    httpd_config_t config = HTTPD_DEFAULT_CONFIG();
    config.server_port = SERVER_PORT;
    config.ctrl_port = SERVER_PORT + 1; 
    config.max_open_sockets = 5; 
    if (httpd_start(&server, &config) == ESP_OK) {
        httpd_register_uri_handler(server, &ws_route);
    }
}

void broadcast_data(float angle, float amplitude, float distance, 
                   const std::vector<float>& waveform, 
                   const std::vector<float>& spectrum) { //json output
    cJSON *root = cJSON_CreateObject();
    cJSON_AddNumberToObject(root, "doa", angle);
    cJSON_AddNumberToObject(root, "amplitude", amplitude);
    cJSON_AddNumberToObject(root, "distance", distance); 

    cJSON *waveArr = cJSON_CreateArray();
    int wave_skip = 4; 
    for(size_t i=0; i<waveform.size(); i+=wave_skip) cJSON_AddItemToArray(waveArr, cJSON_CreateNumber(waveform[i]));
    cJSON_AddItemToObject(root, "waveform", waveArr);

    cJSON *freqArr = cJSON_CreateArray();
    for(float val : spectrum) cJSON_AddItemToArray(freqArr, cJSON_CreateNumber(val));
    cJSON_AddItemToObject(root, "freq_bins", freqArr);

    char *json_str = cJSON_PrintUnformatted(root);
    if (json_str) {
        httpd_ws_frame_t ws_pkt;
        memset(&ws_pkt, 0, sizeof(httpd_ws_frame_t));
        ws_pkt.payload = (uint8_t*)json_str;
        ws_pkt.len = strlen(json_str);
        ws_pkt.type = HTTPD_WS_TYPE_TEXT;
        std::lock_guard<std::mutex> lock(g_client_mutex);
        for (auto it = g_client_sockets.begin(); it != g_client_sockets.end(); ) {
            int fd = *it;
            esp_err_t err = httpd_ws_send_frame_async(server, fd, &ws_pkt);
            if (err != ESP_OK) it = g_client_sockets.erase(it);
            else ++it;
        }
        free(json_str);
    }
    cJSON_Delete(root);
}
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

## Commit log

2025-11-04 Added test snapshot with better filtering
2025-11-24 Add Mecanum motor control implementation
    This file contains the implementation of Mecanum motor controls for a robot, including motor pin definitions, movement functions, LED control, and a web server interface for remote control.
2025-12-03 Create Sound Sensor Code (Not final)
    Done using Arduino IDE
2026-01-29 Update Sound Sensor Code (Not final v2)
2026-02-15 Update Sound Sensor Code (Not final)
2026-04-20 Create ESP32 Files
2026-04-20 Final System Code, for 4/19/2026
    This is the current working system code that will be used to demonstrate.
2026-04-20 Rename ESP32PCBc[1].PcbDoc to ESP32 Files/ESP32PCBc[1].PcbDoc
    [ESP32PCBc[1].PcbDoc]
2026-04-20 Rename 404_ESP_Real[1].PrjPcb to ESP32 Files/404_ESP_Real[1].PrjPcb
    [404_ESP_Real[1].PrjPcb]
2026-04-20 Rename PcbLib[1].PcbLib to ESP32 Files/PcbLib[1].PcbLib
    [PcbLib[1].PcbLib]
2026-04-20 Rename ESP32SchematicPG2[1].SchDoc to ESP32 Files/ESP32SchematicPG2[1].SchDoc
    [ESP32SchematicPG2[1].SchDoc]
2026-04-20 Rename ESP32Schematic[1].SchDoc to ESP32 Files/ESP32Schematic[1].SchDoc
    [ESP32Schematic[1].SchDoc]
2026-04-20 Rename Schlib[1].SchLib to ESP32 Files/Schlib[1].SchLib
    [Schlib[1].SchLib]
2026-04-20 Microphone Array PCB
    PCB Files for Microphone Array
    [PCB_CapstoneArray.PrjPcb, Schlib[1].SchLib]
2026-04-20 Move PCB to Folder
    [PCB_CapstoneArray.PrjPcb]
